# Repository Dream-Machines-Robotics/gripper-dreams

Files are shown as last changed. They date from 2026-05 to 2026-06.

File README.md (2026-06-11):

# Dream Gripper

<p align="center">
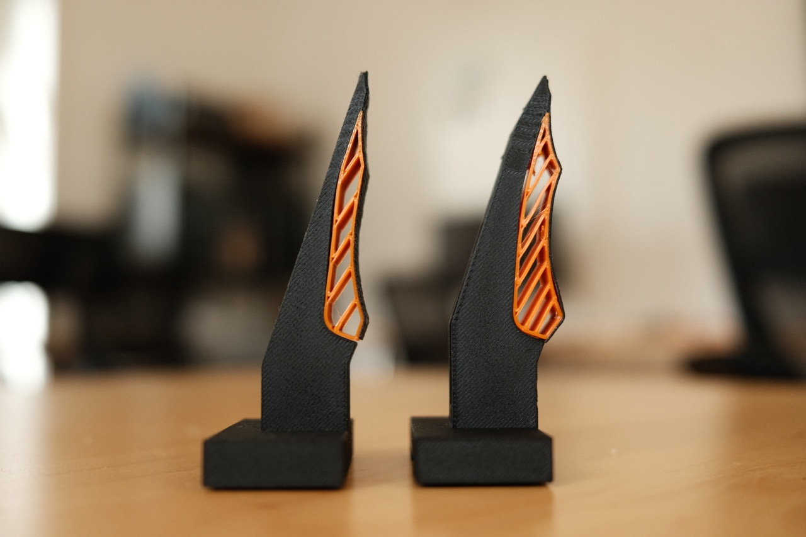
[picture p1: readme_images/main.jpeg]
Dream Gripper mounted on the DK1 robot arm
  
</p>

The Dream Gripper is a 3D-printable, open-source gripper for the DK1 arm from
[The Robot Learning Company](https://www.robot-learning.co/). It is designed to
pick up small objects such as O-rings while still holding larger objects such as
mugs, using only standard 3D-printing materials and grip tape. A single gripper
uses less than EUR 1 of printed material.

## Highlights

- 3D-printable rigid backbone with a soft TPU insert.
- Slim rigid tips for precise contact on small objects.
- Larger compliant contact area for bigger or sharper objects.
- Strong enough for heavy everyday objects while staying easy to reproduce.
- Visible deflection that can help robot learning policies infer grip force.
- Designed around a linear-rail platform.
- Source model and printable STL files included.

## Files

| File | Variant | Purpose |
|---|---|---|
| [Dream Gripper TRLC.f3d](3D-Files/Dream%20Gripper%20TRLC.f3d) | Regular | Fusion 360 source model |
| [Dream Gripper TRLC Jumbo.f3d](3D-Files/Dream%20Gripper%20TRLC%20Jumbo.f3d) | Jumbo | Fusion 360 source model |
| [PLA-CF Backbone.stl](3D-Files/PLA-CF%20Backbone.stl) | Regular | Rigid printed backbone |
| [PLA-CF Backbone Jumbo.stl](3D-Files/PLA-CF%20Backbone%20Jumbo.stl) | Jumbo | Rigid printed backbone |
| [TPU Insert.stl](3D-Files/TPU%20Insert.stl) | Regular | Soft printed insert |
| [TPU Insert Jumbo.stl](3D-Files/TPU%20Insert%20Jumbo.stl) | Jumbo | Soft printed insert |

## Variants

The design currently has two variations:

1. **Regular** - the original gripper design.
2. **Jumbo** - a modified version with reduced backbone bending and more inside
   grip. This helps with wide, flat objects such as PCBs and tasks that need a
   stronger grip on a small surface, such as pulling open a zip bag.

## Gallery

<table>
  <tr>
    <td width="50%">
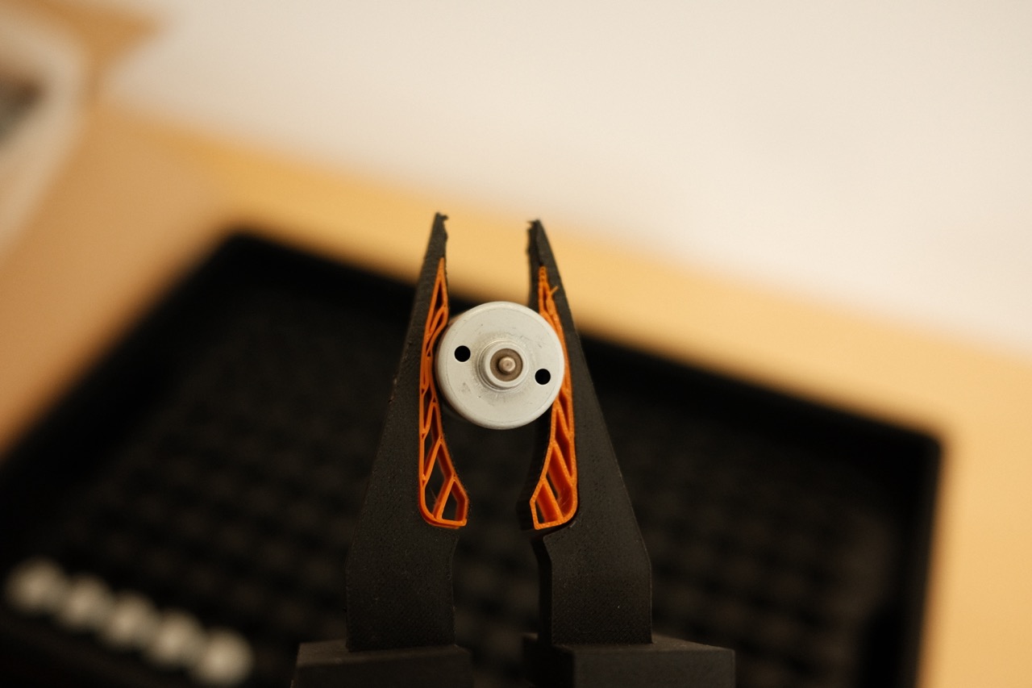
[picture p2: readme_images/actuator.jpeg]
Dream Gripper actuator detail
      
    </td>
    <td width="50%">
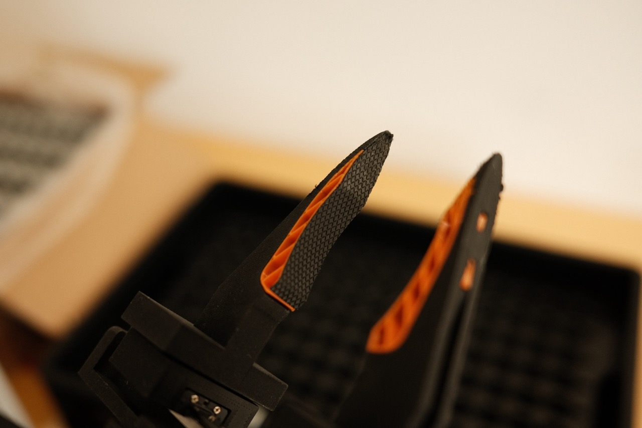
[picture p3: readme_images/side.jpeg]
Side view of the Dream Gripper
      
    </td>
  </tr>
  <tr>
    <td width="50%">
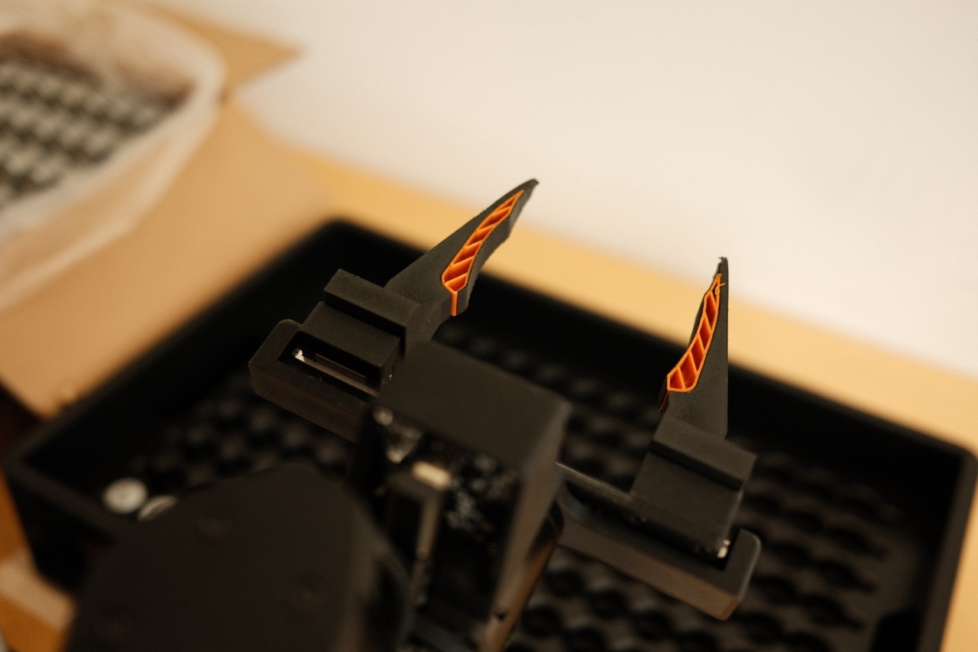
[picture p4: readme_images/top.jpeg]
Top view of the Dream Gripper
      
    </td>
    <td width="50%">
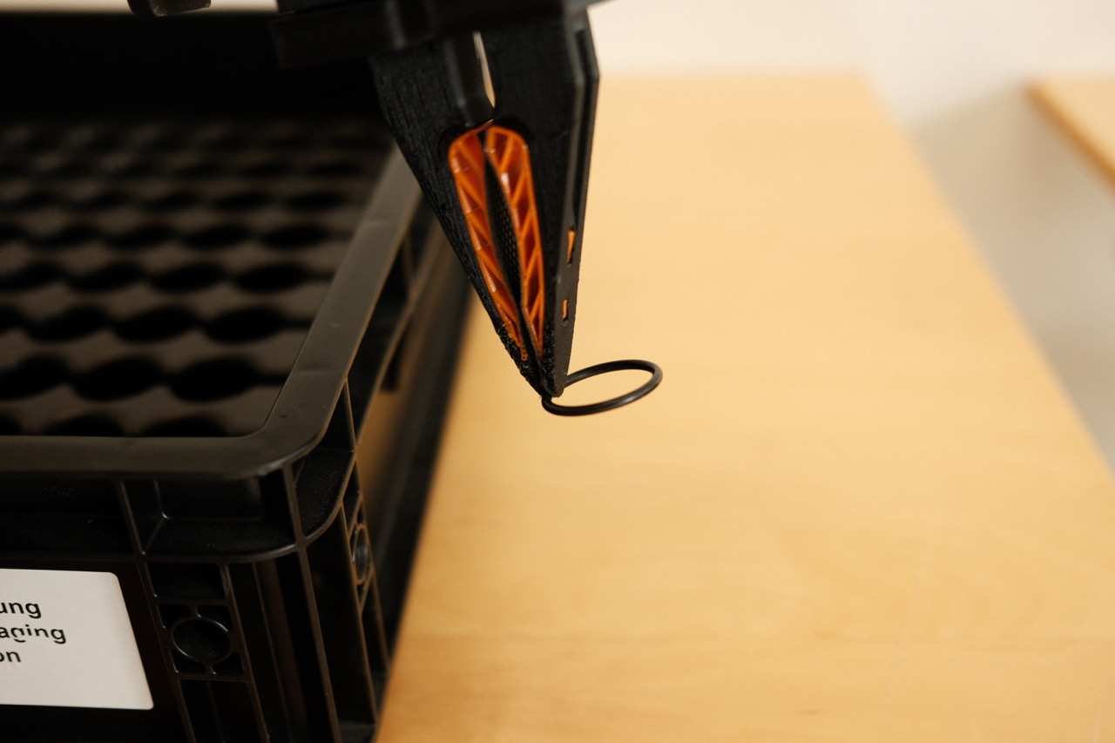
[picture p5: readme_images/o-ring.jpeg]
Dream Gripper picking up an O-ring
      
    </td>
  </tr>
</table>

## Materials

| Component | Material | Example | Price |
|---|---|---|---|
| Rigid backbone | PLA-CF | [Bambu Lab PLA-CF](https://eu.store.bambulab.com/products/pla-cf) | EUR 26.99 |
| Soft insert | TPU95A | [TPU95A filament](https://www.amazon.de/dp/B09KKZLZVR?ref=ppx_yo2ov_dt_b_fed_asin_title) | ~EUR 30.00 |
| Contact surface | Grip tape | [Grip tape](https://www.amazon.de/dp/B0FB8LQ29P?ref=ppx_yo2ov_dt_b_fed_asin_title&th=1) | EUR 16.99 |

## Design Notes

### Gripper Tip

The tip is rigid PLA-CF covered with a thin layer of grip tape. This
**fingernail design** lets the gripper exert more force on small objects while
keeping a slim profile.

### TPU Insert

The middle section uses a soft TPU insert that grips larger objects more firmly
by increasing the contact surface. Objects with sharp corners benefit too: the
TPU wraps the grip tape layer around the edges of the object.

## Assembly

1. Print the backbone in **PLA-CF** and the insert in **TPU95A**.
2. Remove all supports from both parts.
3. Press the TPU insert into the backbone slots. A tight fit is intended.
4. Lay the assembly gripping-side down on a strip of grip tape.
5. Trace the outline onto the back of the tape and cut out the shape.
6. Leave extra tape toward the inside of the gripper so the tape can extend over
   the TPU by a few centimeters on each side. This helps prevent loosening over
   time.

## Credits

Built by **[Sixtus Klein](https://www.linkedin.com/in/sixtus-klein-a41421265/?skipRedirect=true)**
at **[Dream Machines](https://dream-machines.eu/)**.

Jumbo modifications by **[Janne Stiefel](https://jannestiefel.com/)**.

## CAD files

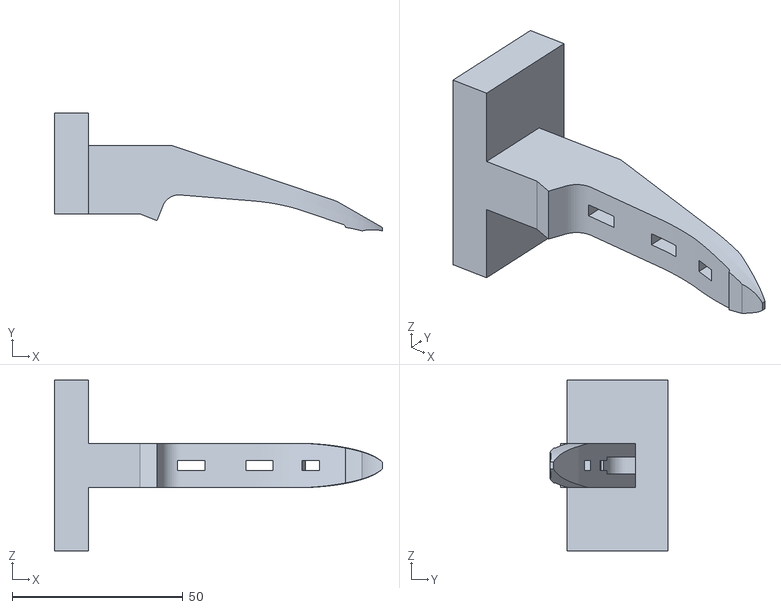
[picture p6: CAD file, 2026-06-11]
3D-Files/PLA-CF Backbone Jumbo.stl
96.0 x 34.5 x 50.0

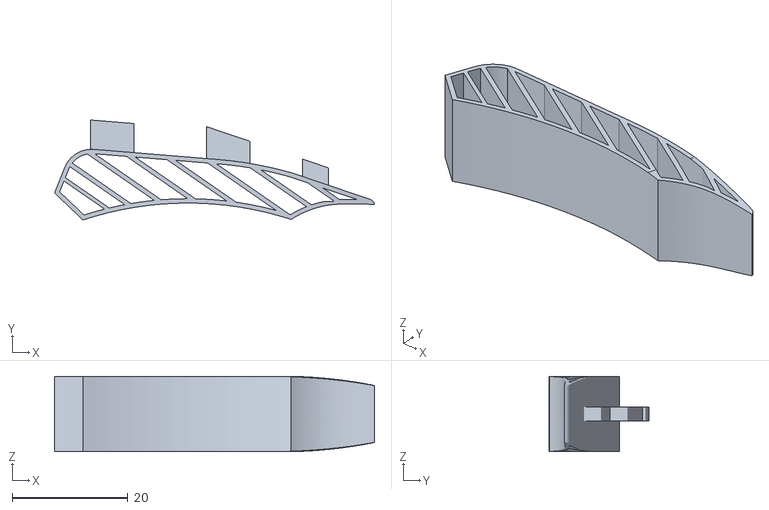
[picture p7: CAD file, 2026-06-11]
3D-Files/TPU Insert Jumbo.stl
55.2 x 17.2 x 13.0

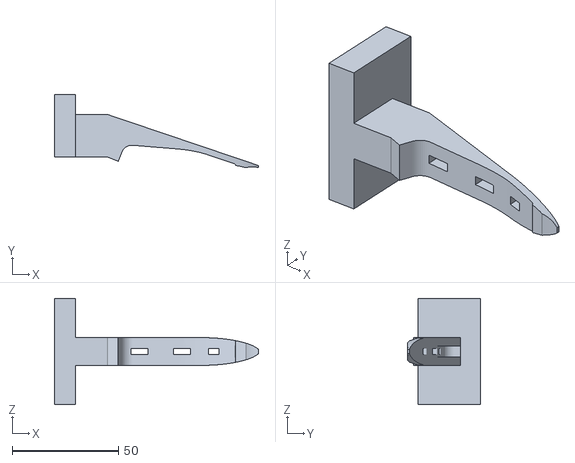
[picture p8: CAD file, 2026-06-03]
3D-Files/PLA-CF Backbone.stl
96.0 x 34.5 x 50.0

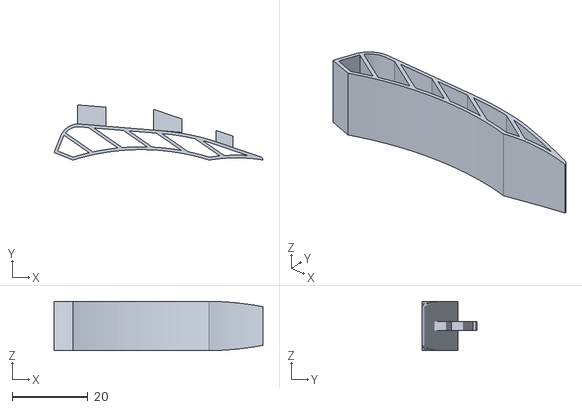
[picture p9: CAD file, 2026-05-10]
3D-Files/TPU Insert.stl
55.2 x 14.6 x 13.0

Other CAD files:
3D-Files/Dream Gripper TRLC Jumbo.f3d
3D-Files/Dream Gripper TRLC.f3d

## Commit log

2026-06-03 Extend base plate and form to fit cleaner to TRLC-DK1
    [Dream Gripper TRLC.f3d, Dream Gripper.f3d, PLA-CF Backbone.stl]
2026-06-11 Rename jumbo 3D files
    [Dream Gripper TRLC Jumbo.f3d, PLA-CF Backbone Jumbo.stl, TPU Insert Jumbo.stl]
